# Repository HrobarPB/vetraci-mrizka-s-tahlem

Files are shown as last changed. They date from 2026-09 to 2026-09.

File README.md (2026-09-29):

# Větrací mřížka s žaluzií ovládanou táhlem zespodu

Plastová větrací mřížka **180 × 250 mm** s nastavitelnou žaluzií, podobná
typu *Dalap GP 180×250 s mechanicky ovládanou žaluzií*. Rozdíl je v ovládání:
místo páčky na mřížce **visí ze spodku rámu otočná tištěná tyč s rukojetí**,
takže mřížku ve výšce ovládne i menší člověk ze země.
Tyč je při pohledu zepředu **vlevo**. Na pravou stranu ji přepne parametr
`ovladani = "vpravo"`.

- rukojetí se otáčí o **půl otáčky**, tři polohy jsou po čtvrtotáčkách:
  **0° zavřeno, 90° napůl, 180° otevřeno**; šipka na rukojeti ukazuje, kde
  mřížka je
- v každé poloze je **zastavovací ploška**, lamely tam drží samy a nic je
  nestáhne dolů; konce drážky jsou pevné dorazy
- tyč se jen otáčí, nahoru ani dolů se nehýbe
- všechny díly mechanismu včetně tyče se **tisknou**, nic se nekupuje
- vzadu je **pevný rošt** a za ním **síťka proti hmyzu**, kupovaná nebo tištěná
- mřížka má dvě části: **montážní deska** zůstává na zdi, **přední kryt**
  s lamelami se sundá po pootočení 4 tištěných zámků, třeba kvůli výměně síťky

Model je parametrický (OpenSCAD) a všechny díly se tisknou **bez podpěr**.

| Otevřeno | Zavřeno | Mechanismus (boční řez) |
|---|---|---|
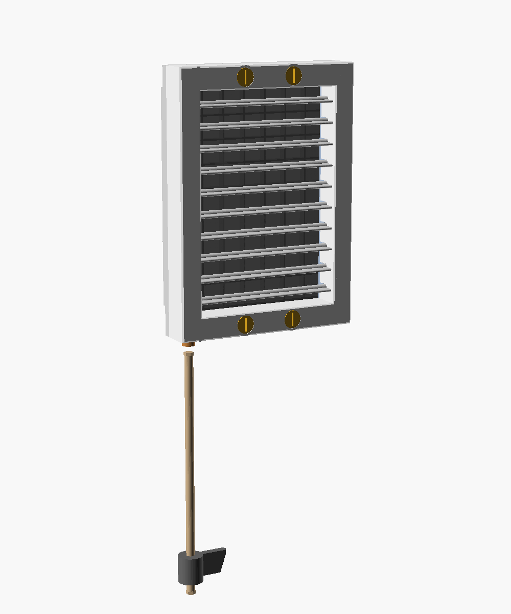
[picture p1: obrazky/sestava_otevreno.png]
otevřeno
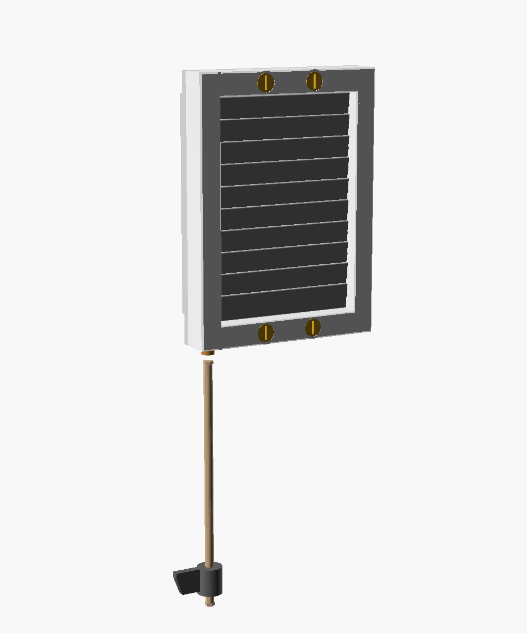
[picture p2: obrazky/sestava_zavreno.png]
zavřeno
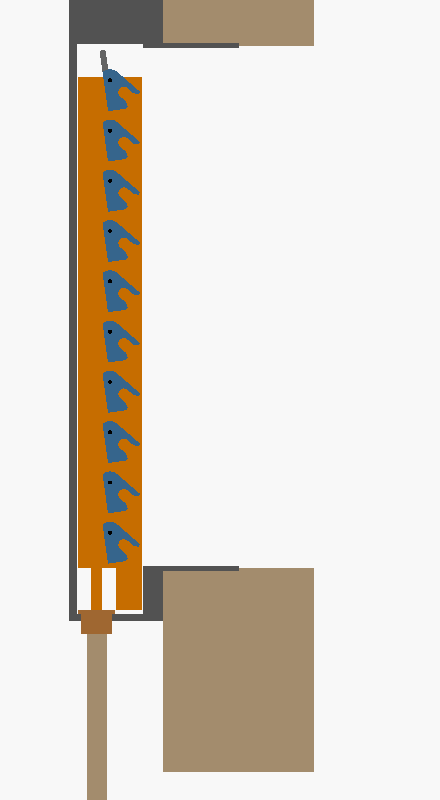
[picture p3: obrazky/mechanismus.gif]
animace
|  |  |  |

## Jak to funguje

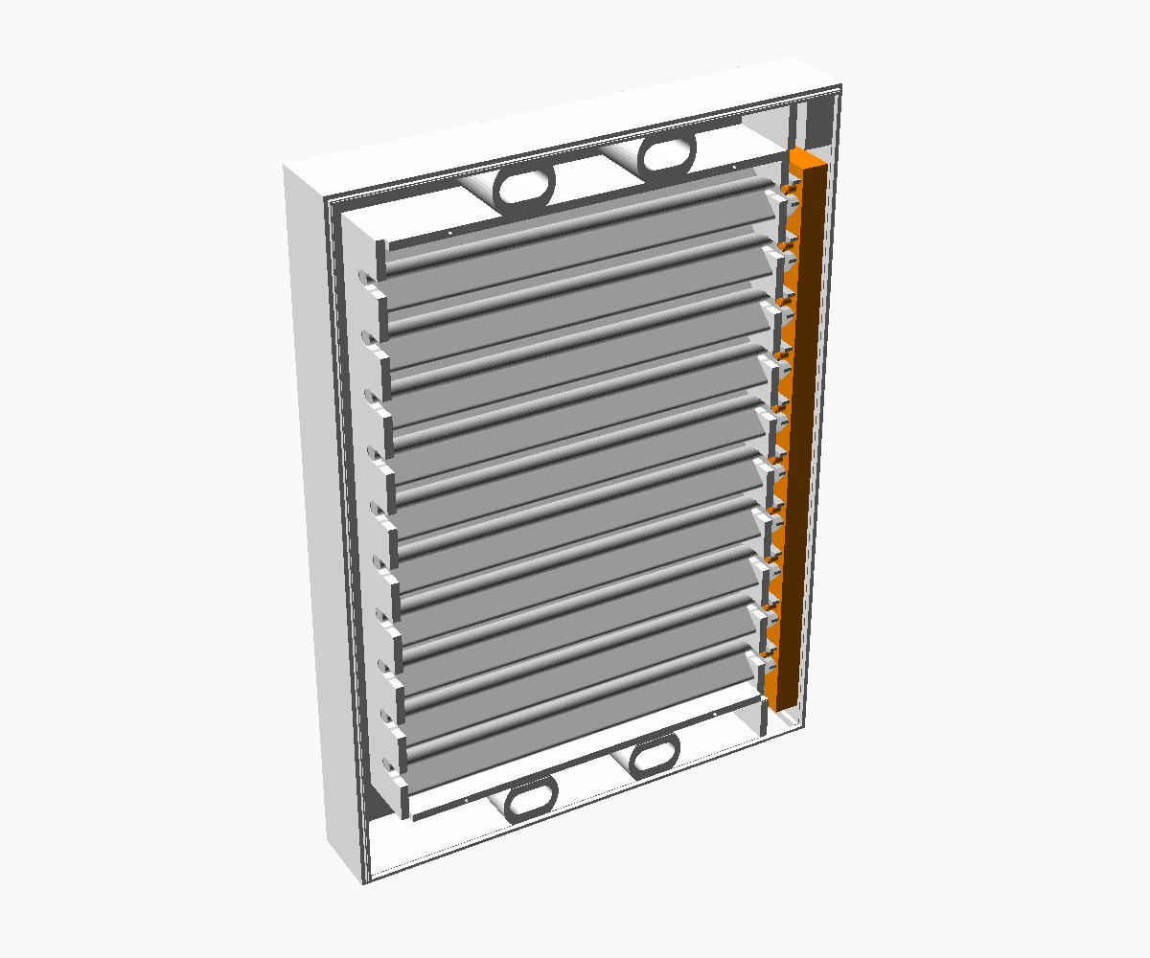
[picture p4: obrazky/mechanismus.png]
mechanismus zezadu


1. Deset vodorovných lamel se otáčí na čepech v rámu.
2. Na konci u táhla má každá lamela **vidlicové rameno** s rozšířeným ústím.
   Rameno je schované v boční komoře rámu, zepředu ho není vidět.
3. V komoře jezdí svislá **ovládací lišta** (oranžová). Její čepy zapadají
   do vidlic všech lamel najednou.
4. Lišta se pohybuje jen nahoru a dolů, **zdvih je 13 mm**. Lamely se přitom
   otočí o 82° z vodorovné polohy do téměř svislé a zavřené lamely se
   překrývají.
5. Pod lištou stojí na dně komory **rotační klín** (vačka): plný kotouč
   Ø 15 mm, stejný princip jako revolverový hloubkový doraz horní frézky.
   Nahoře má vyříznuté ploché stupně a šikmé náběhy a lišta na něm stojí
   **masivní nohou** (6 × 4 mm) s klínovou patkou. Když se kotouč otočí,
   noha vyjede po náběhu na vyšší stupeň nebo sjede na nižší.
6. Kotouč má tři vodorovné **stupně**: v poloze 0° (zavřeno), 90° (napůl)
   a 180° (otevřeno), mezi nimi jsou náběhy asi 40°. Lišta stojí na stupni
   vlastní vahou, takže v otevřené poloze stojí na nejvyšším stupni
   a nemá kam sjet. Když se rukojeť pustí mezi polohami, lišta po náběhu
   sama sjede na nejbližší nižší stupeň. Zbytek kotouče, kam noha nikdy
   nedojede, je plný a o 3 mm vyšší než nejvyšší stupeň: o něj noha za 0°
   a za 180° narazí (pevné dorazy).
7. Kotouč má dole čep, který prochází drážkou ve dně rámu, shora ho
   přitlačuje lišta. Váha tyče visí na kotouči, ne na liště.
8. Do čepu kotouče se zespodu zacvakne **tištěná tyč**: kulatá Ø 8 mm,
   jen konce jsou šestihranné (8 mm přes plošky). Tyč je složená z dílů,
   které se spojují tištěnými **spojkami**, dole je **rukojeť**
   s křidélkem na jednu stranu a šipkou.

Rozložená sestava:

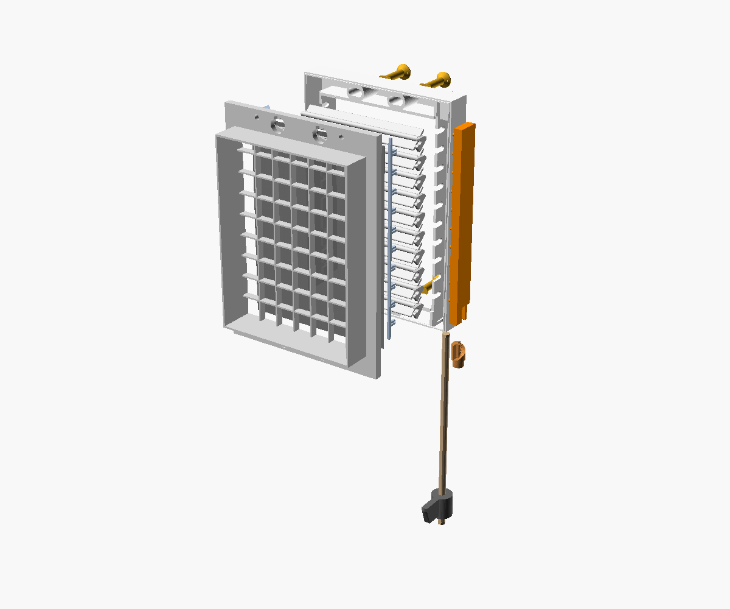
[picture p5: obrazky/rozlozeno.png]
rozloženo


## Rozměry (výchozí nastavení)

| | |
|---|---|
| vnější rozměr rámu | 180 × 250 mm |
| vystoupení ze zdi | 37,5 mm (přední kryt 29,5 + montážní deska 8) |
| světlý průduch (lamely) | 140 × 206 mm |
| otvor ve zdi (zadaný) | 158 × 208 mm |
| límec do otvoru ve zdi | 156 × 206 mm (vůle 1 mm na stranu), **stěny 2 mm**, hloubka 30 mm |
| rošt v montážní desce | 152 × 202 mm, oka cca 22 × 22 mm, žebra 1,6 mm |
| síťka proti hmyzu | přes celý otvor v límci, ustřihnout na **159 × 211 mm** |
| lamely | 10 ks, rozteč 20 mm, šířka 25 mm |
| zdvih lišty | 13 mm, polohy 0° / 90° / 180° |
| osa tyče | vlevo, 11 mm od levého okraje a 26,6 mm od zdi |
| vruty do zdi | 4× Fischer DuoPower 8 × 65 S jen skrz montážní desku, rozteč 100 mm vodorovně a 234 mm svisle, osa 8 mm od horní/dolní hrany (13 mm od otvoru ve zdi) |
| přední kryt k montážní desce | 4 otočné zámky na čtvrt otáčky: šroubovitý náběh, půlkruhová aretace, dorazy; rozteč 50 mm |

> **Otvor ve zdi** je nastavený na 158 × 208 mm (`otvor_sirka`,
> `otvor_vyska`). Límec se podle něj spočítá sám, o 1 mm na každou stranu
> menší (`limec_vule`).

## Díly k tisku

Hotová STL jsou ve složce [`stl/`](stl). Jsou už natočená do tiskové polohy.

| Díl | Soubor | Ks | Poznámka k tisku |
|---|---|---|---|
| Přední kryt (rám) | `ram.stl` | 1 | lícem dolů, potřebuje podložku aspoň **180 × 250 mm** |
| Montážní deska s límcem a roštem | `zadni_deska.stl` | 1 | deskou dolů; pro kupovanou síťku |
| *nebo* montážní deska s tištěnou síťkou | `zadni_deska_se_sitkou.stl` | 1 | místo předchozí; deskou dolů, viz [Síťka proti hmyzu](#síťka-proti-hmyzu) |
| Lamela | `lamela.stl` | **10** | rovnou stranou dolů, rameno nahoru |
| Ovládací lišta | `lista.stl` | 1 | naležato, čepy nahoru |
| Vačka (stupňový doraz) | `vacka.stl` | 1 | nastojato, čepem dolů; 4 perimetry, výplň 100 % |
| Pojistný hřebínek u táhla | `pojistka_u_tahla.stl` | 1 | naležato |
| Pojistný hřebínek protější (se žebry) | `pojistka_protejsi.stl` | 1 | naležato, žebry nahoru |
| Díl tyče (kulatá Ø 8, šestihranné konce, 230 mm) | `tyc.stl` | podle výšky (viz níže) | naležato na plošce; 4 perimetry |
| Spojka dílů tyče | `spojka.stl` | o 1 méně než dílů tyče | nastojato |
| Rukojeť se šipkou | `rukojet.stl` | 1 | zásuvkou nahoru |
| Vodítko tyče na zeď | `voditko.stl` | 0–2 | volitelné, když se tyč při točení moc houpe |
| Otočný klíč zámku | `klic.stl` | **4** | nastojato na rovné straně příčky, hlavou nahoru, bez podpěr; 4 perimetry, výplň 100 % |

**Materiál:** PETG (do interiéru) nebo ASA (na přímé slunce, originál je
také z ASA). PLA nedoporučuji, protože pružné díly (hroty tyče, hřebínky)
z PLA časem povolí nebo prasknou.
**Nastavení:** vrstva 0,2 mm, 3 perimetry, výplň 20 %, **bez podpěr**.
Lištu tiskněte se 4 perimetry, vačku a díly tyče se 4 perimetry a 100 %
výplní (přenášejí otáčení).

## Co koupit

| Položka | Ks | Kde koupit (příklady) |
|---|---|---|
| Hmoždinka **Fischer DuoPower 8 × 65 S** (balení obsahuje zápustné vruty **5 × 80**) | 4 | [KUTIL.cz](https://www.kutil.cz/spojovaci-material-a-kotevni-technika/kotevni-technika/vseobecne-hmozdinky/hmozdinka-duopower-fischer-8x65-1/), [srovnání cen na Heureka](https://www.heureka.cz/?h%5Bfraze%5D=hmo%C5%BEdinka+duopower+fischer+8x65), [technický list Fischer](https://www.fischer-cz.cz/cs-cz/products/bezne-hmozdinky/plastove-hmozdinky/duopower/538256-duopower-8x65-s) |
| Síť proti hmyzu, sklolaminátová, metráž (stačí kus 16 × 22 cm) | 1 | [UNI HOBBY – metráž šedá](https://unihobby.cz/sit-proti-hmyzu-sklovlaknita-metraz-seda), [BAUHAUS – sítě proti hmyzu](https://www.bauhaus.cz/site-proti-hmyzu-245270), [OBI – sítě proti hmyzu](https://www.obi.cz/ochrana-proti-hmyzu/ochranne-site-proti-hmyzu/c/2200), [Onpira – metráž](https://www.onpira.cz/zbozi/site-proti-hmyzu-skelne-vlakno/) |
| Vodítko (volitelné): 2 vruty 3,5 × 30 mm a hmoždinky 5 mm | 2 | [Heureka – hmoždinka 5 mm s vrutem](https://www.heureka.cz/?h%5Bfraze%5D=hmo%C5%BEdinka+5+mm+s+vrutem) |

Mechanismus i tyč jsou celé tištěné, na ovládání se nic nekupuje.

### Délka tyče

Tyč se skládá z dílů `tyc.stl` (každý 230 mm, parametr `tyc_dil`), mezi nimi
jsou spojky a dole rukojeť:

```
vzdálenost od spodku mřížky ke spodku rukojeti ≈ počet dílů × 233 mm + 17 mm
```

Příklad: mřížka má spodek ve 240 cm, rukojeť má být kolem 150 cm, tedy
90 cm: **4 díly** (949 mm, rukojeť ve 145 cm) a 3 spojky. Na přesnou délku
změňte `tyc_dil` (třeba 4 díly po 215 mm) a díly přegenerujte.

## Sestavení předního krytu

1. **Očistěte díly.** Lamela se musí v drážkách „U“ rámu otáčet volně. Když
   drhne, přejeďte čepy smirkem. Kotouč dorazu se musí volně otáčet
   v drážce ve dně.
2. Rám položte **lícem dolů** na stůl. Komora mechanismu je teď při pohledu
   zezadu **vpravo**.
3. **Vložte kotouč dorazu:** zezadu ho zasuňte čepem do drážky ve dně
   komory (kotouč projde výřezem ve spodku přepážky). Natočte ho do polohy
   **90°** (napůl): prostřední stupeň je na straně u vnější stěny rámu.
4. **Vložte lamely** jednu po druhé zezadu, čepem do drážek „U“. Každou
   natočte **napůl** (asi 41° od vodorovné), tak aby otevřená vidlice ramene
   mířila **rovně dozadu**, tedy kolmo od stolu nahoru.
5. **Zasuňte lištu** zezadu do komory, čepy k lamelám, nohou dolů. Čepy vjedou do vidlic všech lamel najednou (ústí vidlic jsou
   rozšířená, takže lamely nemusí být natočené přesně) a noha dosedne
   na prostřední stupeň kotouče.
6. **Zatlačte oba pojistné hřebínky** do vybrání na horní hraně přepážek,
   až **cvaknou**. Jejich prsty zajistí čepy lamel v drážkách. Každý prst je
   rozdělený na dvě pružné poloviny s výstupky, které zapadnou do drážek ve
   stěnách krytu, takže hřebínek drží i v sundaném krytu. Vytáhnout se dá
   silou (výstupky mají šikmé boky). Sílu západky mění `hrebinek_zapadka`.

   Hřebínky jsou dva různé díly. `pojistka_u_tahla` patří na přepážku vedle
   mechanismu (při táhle vlevo je to levý). `pojistka_protejsi` patří na
   volně stojící stěnu průduchu na druhé straně (při táhle vlevo pravý).
   Ten má navíc žebra, která vyplní mezeru mezi stěnou průduchu a vnější
   stěnou krytu a opřou se o ni. Hřebínek se tak nemůže naklonit ani
   posunout do strany a výstupky prstů nevyskočí z drážek. Žebra jsou mezi
   prsty, takže prsty dál pruží.

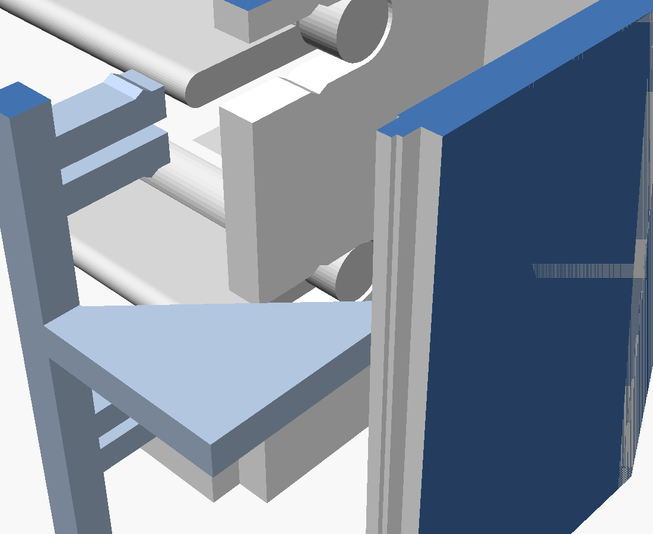
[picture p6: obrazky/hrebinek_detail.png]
detail západky hřebínku
   

   *Hřebínek (modrý) vytažený z krytu: každý prst je rozdělený na dvě pružné
   poloviny s výstupky, ve stěnách drážek „U“ v krytu jsou proti nim drážky.*
7. **Vyzkoušejte chod:** otáčejte kotoučem za čep, který vyčnívá zespodu
   rámu (rám držte svisle, jak bude na zdi, lišta stojí vlastní vahou).
   Na 0°, 90° a 180° musí lamely zůstat stát, mezi nimi se musí otáčet
   všechny současně a lehce.
8. **Klíče zámků** (bez lepidla a bez šroubů) se zasouvají až při nasazení
   krytu na montážní desku, viz [Montáž na zeď](#montáž-na-zeď-fischer-duopower-8--65-s),
   krok 6.

## Zámek krytu (jak funguje)

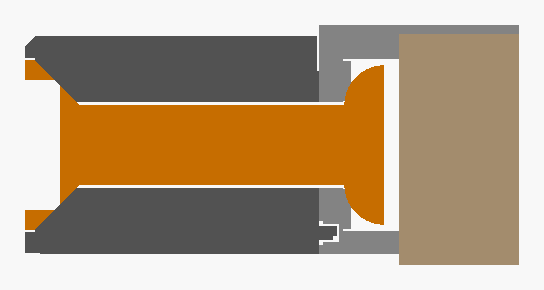
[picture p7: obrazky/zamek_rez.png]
řez zámkem v zamčené poloze


*Řez osou zámku: vlevo zápustná hlava klíče v líci krytu, kulatý dřík skrz kryt,
vpravo půlkulatá příčka za plným dnem zámku v montážní desce, úplně vpravo zeď.*

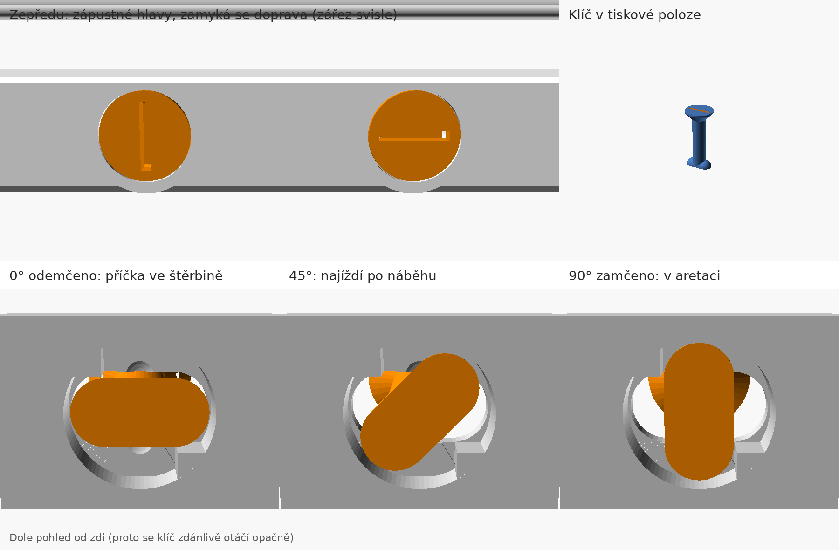
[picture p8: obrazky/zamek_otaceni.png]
otáčení klíče


*Nahoře zepředu: hlavy klíčů (Ø 17 mm) jsou zapuštěné a zarovnané s lícem
krytu a otáčejí se v kuželovém lůžku; zářez svisle = zamčeno, vodorovně =
odemčeno. Vpravo klíč v tiskové poloze. Dole pohled od zdi do montážní
desky: příčka se otáčí v kulaté kapse montážní desky za krytem, v krytu je jen
kulatý dřík. Vodorovnou štěrbinu v krytu hlava zakryje v každé poloze.*

Zámek je udělaný jako současné vačkové zámky na čtvrt otáčky (např. u
rozvaděčů): příčka po **šroubovitém náběhu** postupně přitáhne kryt, na konci
zapadne do **aretace** a **doraz** nedovolí přetočení. Všechny tvary, které
se o sebe opírají, jsou **zaoblené (půlkulaté)**: nemají ostré hrany, které
by soustředily napětí a vyrývaly se do plastu.

- **Klíč:** zápustná kulatá hlava Ø 17 mm se zkosením 45° sedí v kuželovém
  lůžku v líci krytu, zarovnaná s lícem, a sama se vystředí. Kulatý dřík
  Ø 8 mm a **půlkulatá příčka** (Ø 8 mm, rovnou stranou ke zdi, zaoblené
  konce). Tiskne se nastojato na rovné straně příčky, hlavou nahoru, bez
  podpěr. Průřez dříku Ø 8 mm unese v tahu i napříč vrstvami řádově přes
  1000 N, zámek přitom nese jen desítky N.
- **Náběh:** za vodorovnou štěrbinou v montážní desce je plné dno 2,4 mm,
  pevně spojené se zbytkem desky a tištěné celou plochou na podložce, a na
  něm šroubovitý náběh. Příčka se točí v kulaté kapse, okolo je deska plná
  až k okraji. Příčka po náběhu najíždí a kryt se přitáhne.
- **Aretace:** v zamčené poloze příčka zapadne do půlkruhového lůžka
  vytvarovaného přesně podle ní a zámek **cvakne**. Přesah 0,3 mm drží
  kryt přitažený. Aby se zámek povolil, musí příčka vyjet zpátky přes
  hranu aretace (0,35 mm), takže se sám neotevře.
- **Dorazy:** klíč se točí jen jedním směrem a jen o čtvrt otáčky. Dorazy
  jsou plné bloky přes celou hloubku kapsy (až po zadní plochu desky),
  srostlé s její stěnou a s rovným čelem, takže se přes ně oblá příčka
  nepřetlačí.
- **Stejný směr zasunutí:** štěrbina v krytu i v montážní desce je
  vodorovná, klíč se zasune skrz oba díly najednou.
- **Obvodová polodrážka (lip and groove):** zadní hrana stěn krytu má po
  celém obvodu límeček 1,4 × 1,8 mm se zúženou špičkou a v čele montážní
  desky je pro něj drážka s vůlí 0,2 mm. Kryt se na desce vystředí ve
  všech směrech dřív, než se zasunou klíče, takže štěrbiny v obou dílech
  jsou přesně proti sobě. Spára mezi díly je navíc zakrytá.
- **Ovládání:** mincí nebo plochým šroubovákem v hlubokém zářezu (3,5 mm);
  zamyká se **doprava** (po směru hodin při pohledu zepředu); zářez **svisle = zamčeno**,
  **vodorovně = odemčeno**.

Zámek je tuhý (nic v něm nepruží), proto rozhoduje přesnost tisku. Nejdřív
vytiskněte jeden klíč a kousek desky se zámkem. Když jde zámek moc ztuha,
zmenšete `klic_predpeti` (např. 0,15) a `aretace_hl` (např. 0,2); když kryt
drží volně, `klic_predpeti` zvětšete.

## Montáž na zeď (Fischer DuoPower 8 × 65 S)

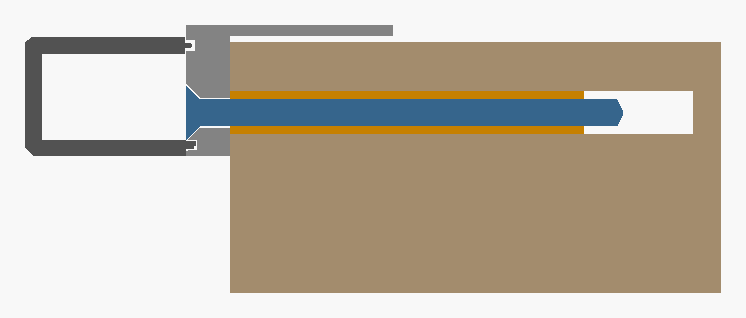
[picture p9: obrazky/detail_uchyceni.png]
detail uchycení


Na zeď se přišroubuje jen **montážní deska** (8 mm). Zápustné hlavy vrutů
5 × 80 jsou v rovině jejího čela, takže je přední kryt zcela zakryje. Vrut
jde do hmoždinky 72 mm (Fischer předepisuje aspoň 70 mm).

1. Montážní desku zasuňte límcem do otvoru ve zdi a srovnejte do vodováhy.
   Skrz 4 otvory označte místa pro hmoždinky a desku sundejte.
2. Vyvrtejte díry **Ø 8 mm, hloubka aspoň 85 mm**. Do cihly a porobetonu
   vrtejte bez příklepu. Vyfoukejte prach.
3. Hmoždinky zatlučte **do roviny zdi**.
4. Montážní desku přišroubujte vruty 5 × 80. Hlavy musí zapadnout do
   zahloubení v rovině čela desky.
5. **Síťka:** kupovanou síťku 159 × 211 mm nabodněte na 4 malé trny na zadní
   straně předního krytu (u horního a dolního okraje průduchu). Trny ji
   drží, takže při nasazování nespadne. (U montážní desky s tištěnou síťkou
   tento krok odpadá.)
6. **Nasaďte přední kryt** na montážní desku tak, aby límeček na zadní
   hraně krytu zapadl po celém obvodu do drážky v desce. Pak do každého otvoru v líci krytu zasuňte klíč
   se zářezem **vodorovně** (příčka projde vodorovnou štěrbinou v krytu
   i v desce, hlava zapadne do zápustného lůžka). Klíč přitlačte a otočte
   mincí nebo šroubovákem o **čtvrt otáčky doprava** (po směru hodin), až
   je zářez **svisle** a zámek cvakne. Zářez v hlavě klíče je 3,5 mm
   hluboký, mince nebo šroubovák se do něj dobře opře.
7. **Tyč:** díly tyče zasuňte do spojek a dole do rukojeti, až **cvaknou**
   (hroty jsou rozdělené a mají západky). Horní hrot zasuňte zespodu do
   čepu kotouče, až cvakne. Šestihran jde zasunout v šesti natočeních: když
   jsou lamely zavřené (0°, kotouč na dorazu), zasuňte rukojeť tak, aby
   šipka mířila **dopředu od zdi**. Po čtvrt otáčce (šipka do strany) je
   mřížka **napůl**, po půl otáčce (šipka **ke zdi**) **otevřená**. Opačným
   směrem se rukojeť neotočí, drží ji doraz ve vačce. Pevným tahem jdou
   hroty zase vytáhnout.
8. Pokud se tyč při točení houpe, přišroubujte doprostřed její délky
   **vodítko**. Tyč se do něj dá zacvaknout i dodatečně.

> ⚠️ **Vzdálenost od okraje otvoru ve zdi.** Otvor 208 mm je vysoký, nad ním
> i pod ním zbývá v mřížce 250 mm jen 21 mm. Vruty jsou proto co nejblíž
> vnější hraně desky (osa 8 mm od hrany, dál to nejde kvůli hlavě vrutu):
> osa hmoždinky je 13 mm od otvoru a mezi vývrtem Ø 8 a otvorem zbývá
> **asi 9 mm zdiva**. Vrtejte bez příklepu a vruty utahujte citlivě.
> Minimální vzdálenost od okraje pro váš materiál uvádí technický list
> Fischer. Víc místa dá jen vyšší mřížka (`vyska`), ta se ale nad 250 mm
> nevejde na běžné tiskové podložky. Model při změně parametrů vypíše,
> kolik zdiva zbývá.

## Síťka proti hmyzu

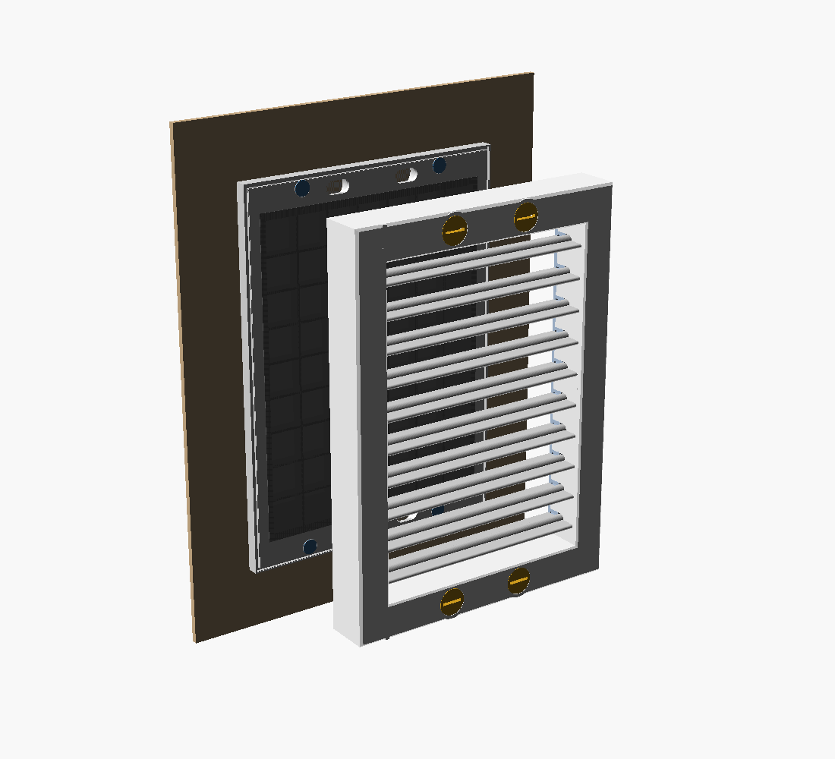
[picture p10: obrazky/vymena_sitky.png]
výměna síťky: montážní deska na zdi, přední kryt sundaný


| Zezadu | Rozloženo (tištěná síťka) |
|---|---|
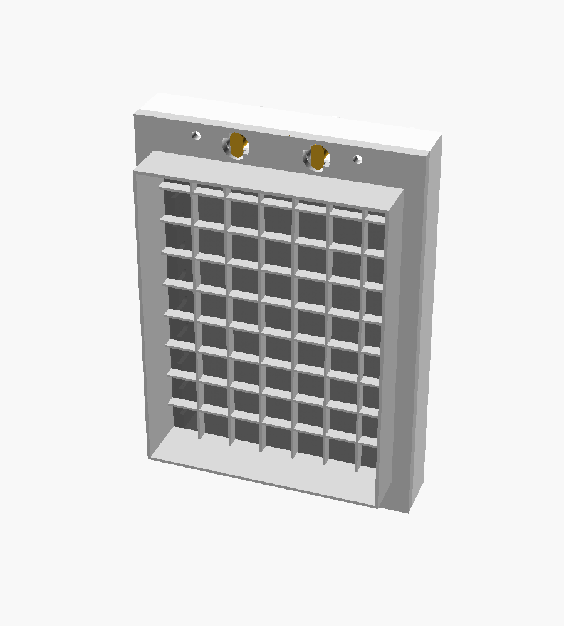
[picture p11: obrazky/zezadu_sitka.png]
zezadu
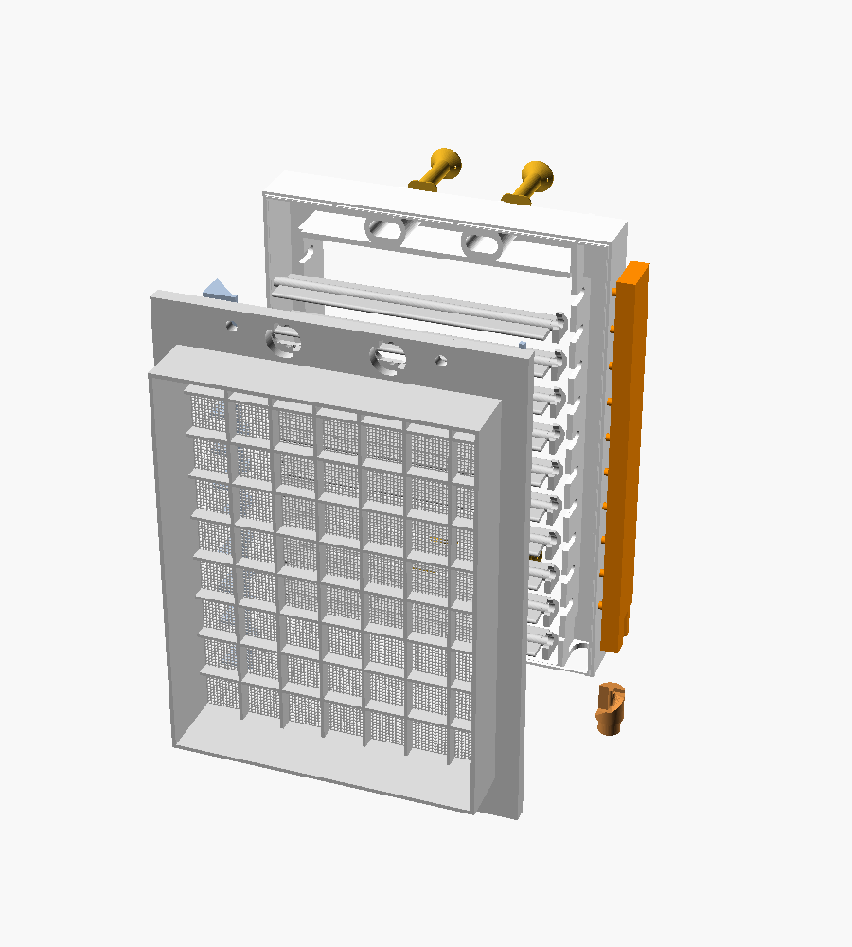
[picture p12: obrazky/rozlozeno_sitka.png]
rozloženo se síťkou
|  |  |

Síťka je **uprostřed mřížky, sevřená mezi předním krytem a montážní
deskou**. Drží ji po celém obvodu 4 otočné klíče, takže nemůže vypadnout ani
se po okraji vysunout. Hned za ní je **pevný rošt** v montážní desce, který
ji podepře a nepustí dovnitř ptáky. Před ní je 1,5 mm volného místa
k lamelám.

**Výměna nebo vyčištění síťky:** mincí otočte 4 klíče zářezem vodorovně,
vytáhněte je, vytáhněte tyč z čepu kotouče a přední kryt sundejte. Montážní deska zůstane na zdi a síťka je
hned přístupná.

**Kupovaná síťka:** ze sklolaminátové sítě proti hmyzu ustřihněte obdélník
**159 × 211 mm** (pokryje celý otvor v límci). Přední kryt má pro síťku lůžko hluboké 0,25 mm, takže ji
montážní deska pevně stiskne.

**Tištěná síťka:** vytiskněte `zadni_deska_se_sitkou.stl` místo
`zadni_deska.stl`. Síťka je plochá mřížka v prvních dvou vrstvách montážní
desky: vlákna v obou směrech leží celou plochou na podložce, nic nevisí ve
vzduchu. Oka 1,2 × 1,2 mm, tloušťka **0,8 mm (4 vrstvy po 0,2 mm)**, aby
se síťka při sundávání z podložky nelámala (parametr `tistena_tl`). Tiskne se deskou dolů na čistou
podložku, výška vrstvy **0,2 mm**, šířka extruze 0,45–0,5 mm, bez
„ironing“. Pokud slicer vlákna vynechá, zvětšete `tistena_vlakno` na 0,6.
Rozteč lze změnit parametrem `tistena_roztec`.

Rošt ubere asi 12 % průřezu, síťka proti hmyzu dalších zhruba 30–40 %.
S tím je potřeba počítat, pokud je větrání na hraně.

## Úpravy modelu

Otevřete `mrizka.scad` v [OpenSCAD](https://openscad.org) (2021.01 nebo
novější). V panelu *Customizer* lze měnit hlavně:

- `ovladani`: strana táhla při pohledu zepředu (`vlevo` nebo `vpravo`)
- `sirka`, `vyska`: vnější rozměr rámu
- `pocet_lamel`, `roztec`, `sirka_lamely`: počet a velikost lamel.
  Světlý průduch a okraje se dopočítají samy.
- `otvor_sirka`, `otvor_vyska`: světlý otvor ve zdi; límec se spočítá sám
  (`limec_vule`), nebo ho zadejte ručně (`limec_sirka`, `limec_vyska`)
- `vrut_od_okraje`: vzdálenost vrutu od hrany desky (menší = dál od otvoru)
- `tl_desky`, `roztec_sroubu`, `hlava_sroubu`: montážní deska a vruty do
  zdi (výchozí hodnoty pro Fischer DuoPower 8 × 65 S s vrutem 5 × 80)
- `roztec_klicu`, `klic_predpeti`, `aretace_hl`, `dno_zamku`: zámky předního krytu
  (viz [Zámek krytu](#zámek-krytu-jak-funguje))
- `bok_protejsi`: šířka bočního okraje bez mechanismu (výchozí 20 mm = souměrný kryt)
- `hrebinek_zapadka`: výška výstupků západky pojistných hřebínků
- `sitka`: `kupovana`, `tistena` nebo `zadna`; `sitka_tl`: hloubka lůžka
  pro kupovanou síťku; `rost_roztec`, `rost_zebro`: pevný rošt;
  `tistena_roztec`, `tistena_vlakno`: tištěná síťka
- `tyc_s`, `tyc_dil`: tyč (šestihran konců přes plošky, délka dílu)
- `vacka_ploska`: šířka stupňů kotouče dorazu ve stupních (na každou stranu)
- `dil`: co se vykreslí (sestava, řez, schéma, rozložený pohled nebo
  jednotlivé díly pro tisk)
- `otevreni`: poloha žaluzie v náhledu (0 až 1)

Model obsahuje kontroly (`assert`), které upozorní na nesmyslnou kombinaci
parametrů.

**Kontrola kolizí a přegenerování STL a obrázků:**

```bash
./skripty/export.sh                              # výchozí rozměry
./skripty/export.sh -D vyska=300 -D pocet_lamel=12   # vlastní rozměry
```

Skript nejdřív spustí `kontrola.scad`. Ta ve 41 polohách mezi zavřeno
a otevřeno ověří, že lamely nenarážejí do sebe ani do rámu, ramena nenarážejí
do komory ani do kotouče dorazu, čepy lišty zůstávají
v rovné části vidlic a lišta nenarazí na kotouč ani horní doraz. Teprve potom skript
vygeneruje STL, obrázky a animaci.

## Ladění

- **Rukojeť jde ztuha:** přejeďte smirkem stupně a náběhy kotouče a patku
  lišty, zkontrolujte, že se kotouč volně točí v drážce ve dně.
- **Lišta nesjíždí dolů na nižší stupeň:** lamely drhnou, uvolněte je
  (čepy v drážkách „U“, vidlice).
- **Hrot tyče drží v zásuvce málo nebo moc:** výšku západek mění `zub_v`
  v sekci *Hidden*.
- **Lamely drhnou:** zvětšete vůle, tedy `r_osa + 0.2` v drážkách „U“,
  nebo zabruste čepy.
- **Zavřené lamely nedoléhají:** úhel `uhel_zavreni` lze zvednout až k mezi,
  kterou hlídá `assert` (výchozí 82° nechává mezi lamelami 0,4 mm).

## ⚠️ Důležité upozornění

Pokud mřížka přivádí **spalovací vzduch pro plynový spotřebič** (kotel,
karma, sporák v bytě s komínovým spotřebičem), **nesmí být uzavíratelná**.
Plynárenská pravidla (TPG 704 01) uzavíratelné větrací otvory pro přívod
spalovacího vzduchu nepovolují. Tuto mřížku tam nepoužívejte. Hrozí otrava
oxidem uhelnatým.

## Alternativy ovládání

Kdyby tyč překážela, dá se vytáhnout z čepu kotouče a nosit zvlášť jako
klíč: zasune se jen při ovládání.

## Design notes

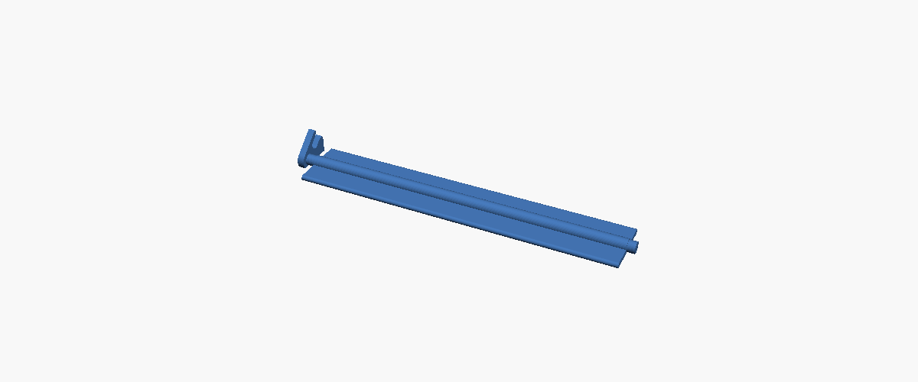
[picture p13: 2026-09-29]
obrazky/lamela.png

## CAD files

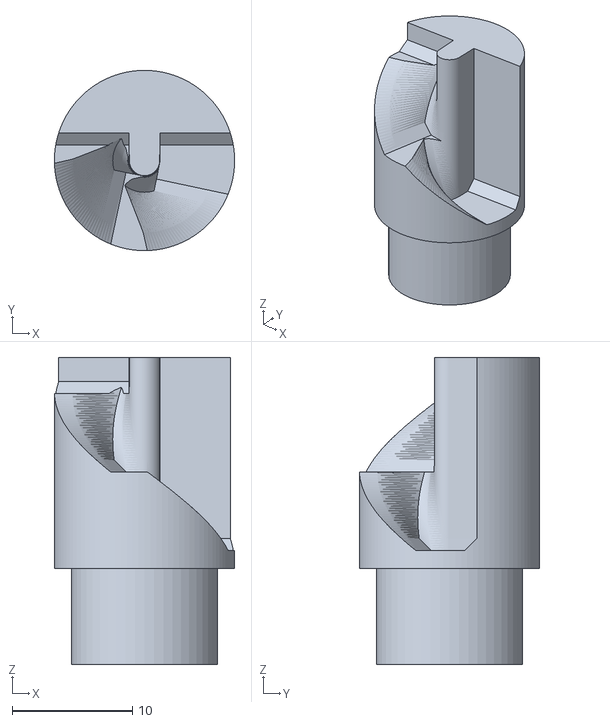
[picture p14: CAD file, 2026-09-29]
stl/vacka.stl
15.0 x 15.0 x 25.5

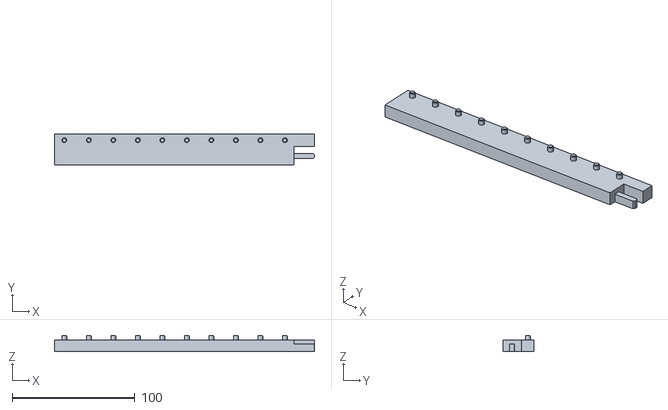
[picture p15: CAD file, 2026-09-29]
stl/lista.stl
212.2 x 25.5 x 13.2

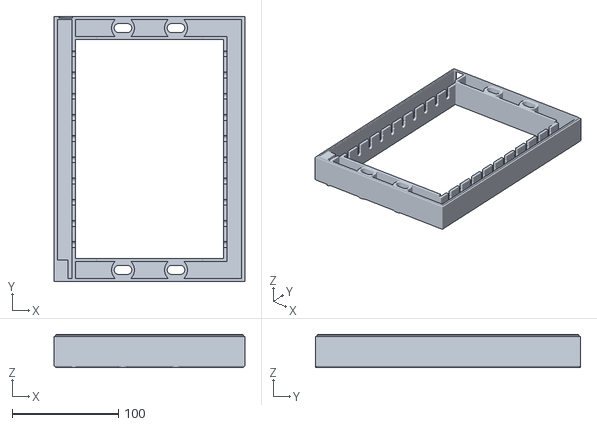
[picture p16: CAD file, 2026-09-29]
stl/ram.stl
180.0 x 250.0 x 31.3

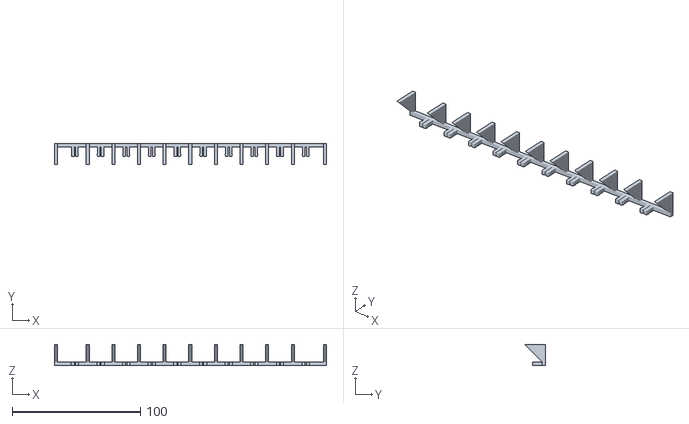
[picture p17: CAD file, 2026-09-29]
stl/pojistka_protejsi.stl
212.2 x 16.4 x 16.7

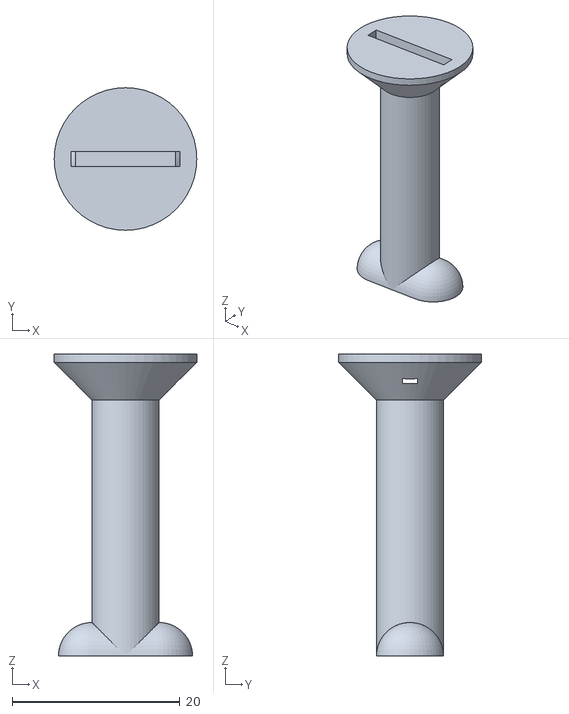
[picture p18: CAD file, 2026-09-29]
stl/klic.stl
17.0 x 17.0 x 36.0

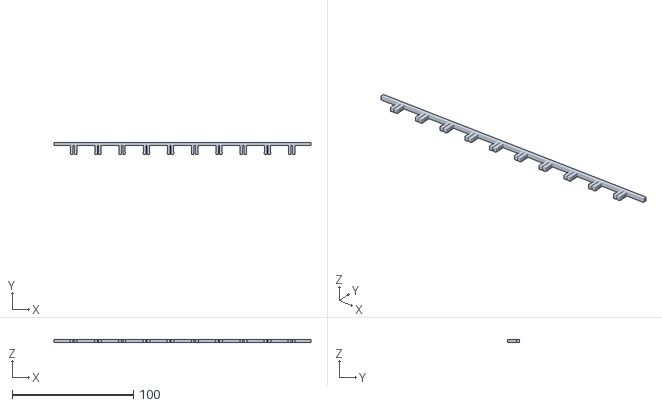
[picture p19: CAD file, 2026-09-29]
stl/pojistka_u_tahla.stl
212.2 x 10.2 x 2.80

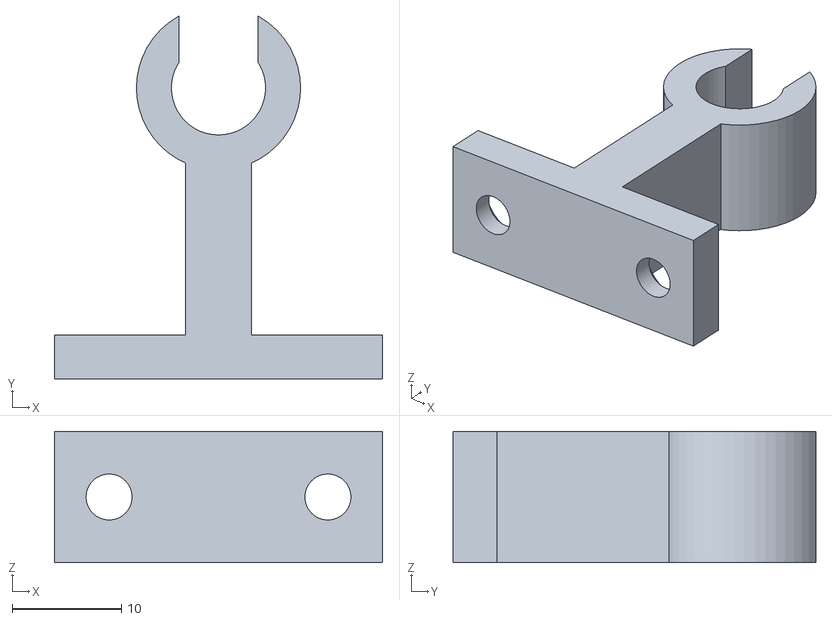
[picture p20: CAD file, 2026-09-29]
stl/voditko.stl
30.0 x 33.2 x 12.0

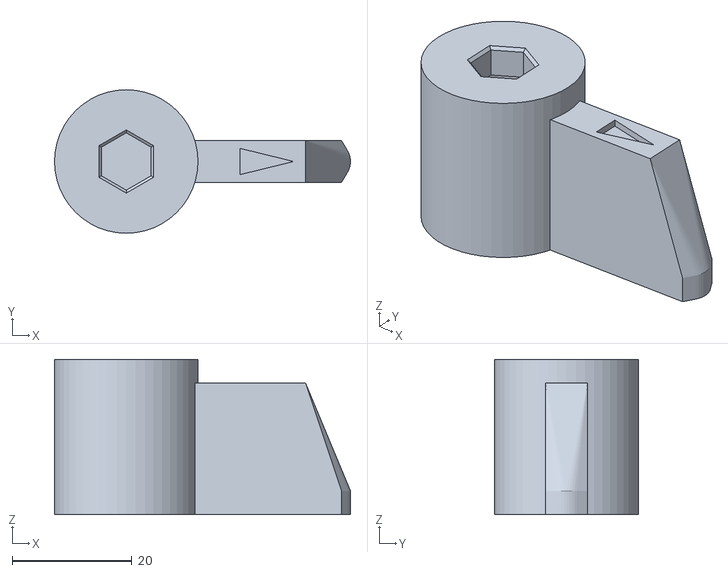
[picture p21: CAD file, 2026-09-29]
stl/rukojet.stl
49.5 x 24.0 x 26.0

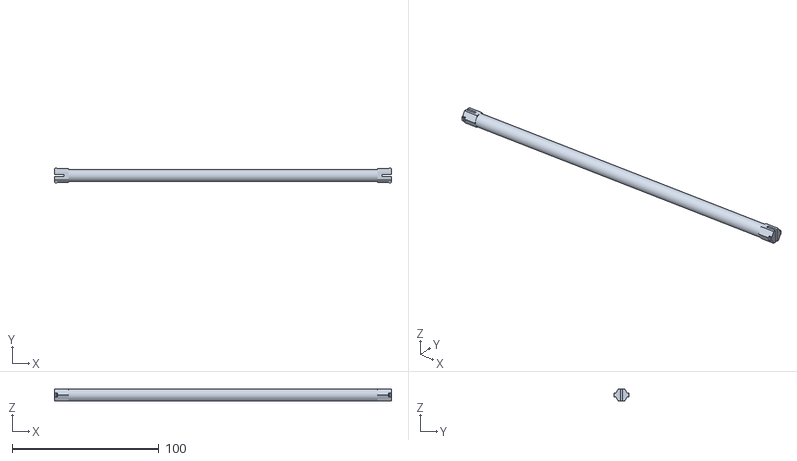
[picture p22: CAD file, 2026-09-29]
stl/tyc.stl
230.0 x 10.3 x 8.00

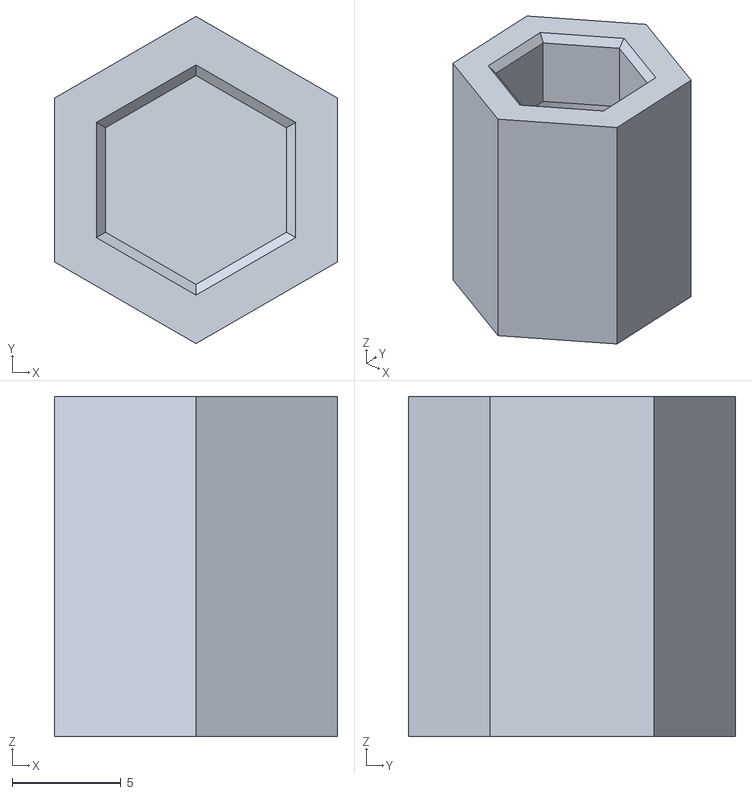
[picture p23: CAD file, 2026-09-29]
stl/spojka.stl
13.0 x 15.0 x 15.6

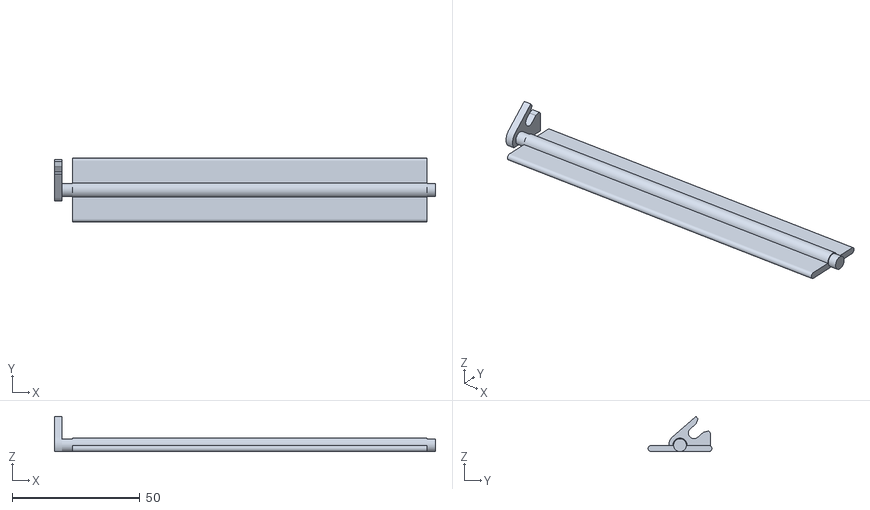
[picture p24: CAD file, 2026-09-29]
stl/lamela.stl
149.3 x 25.0 x 13.8

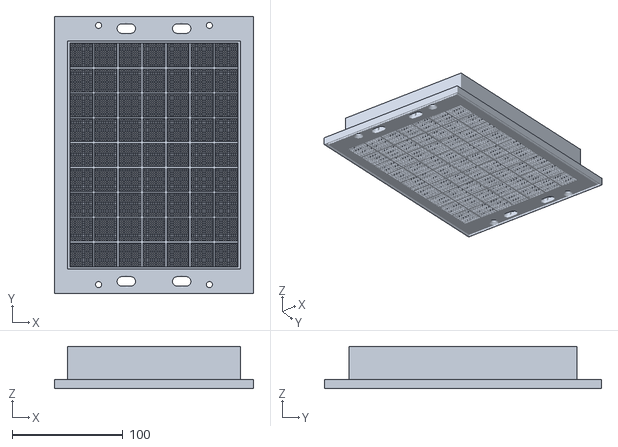
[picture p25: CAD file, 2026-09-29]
stl/zadni_deska_se_sitkou.stl
180.0 x 250.0 x 38.0

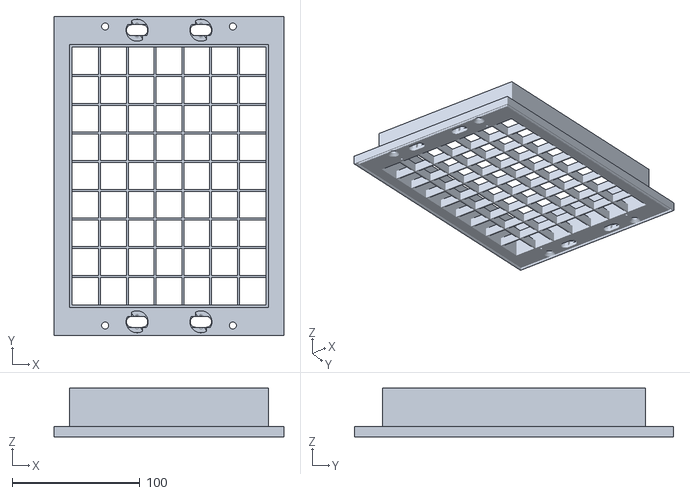
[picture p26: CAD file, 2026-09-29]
stl/zadni_deska.stl
180.0 x 250.0 x 38.0

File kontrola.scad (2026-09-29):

// Kontrola kolizí mechanismu v celém rozsahu pohybu (2D řezy).
// Výsledek musí být PRÁZDNÝ ("Current top level object is empty").
// Spuštění:  openscad -o kolize.svg kontrola.scad
include <mrizka.scad>
dil = "nic";
kroky = 40;
big = 1000;

module lamely2d(phi) for (i = [0:N-1]) translate([y_ax, zl(i)]) rotate(phi) lamela_profil();
module ramena2d(phi) for (i = [0:N-1]) translate([y_ax, zl(i)]) rotate(phi) rameno_profil();
module cepy2d(s) for (i = [0:N-1]) translate([y_pin, zl(i) + s]) circle(r = r_cep);

// stěny v řezu průduchem: horní a dolní okraj (vepředu je okno, vzadu otvor)
module steny_A() {
    translate([-big/2, -big]) square([big, big + tb - eps]);
    translate([-big/2, H - tb + eps]) square([big, big]);
    translate([-big, -big/2]) square([big + 0 - eps, 2*big]);          // před lícem (y < 0)
    translate([D + sd + limec_hloubka + eps, -big/2]) square([big, 2*big]);
}
// stěny v řezu ramen: čelo, zadní deska, dno, strop komory
module steny_B() {
    translate([-big, -big/2]) square([big + st - eps, 2*big]);
    translate([D + eps, -big/2]) square([big, 2*big]);
    translate([-big/2, -big]) square([big, big + st - eps]);
    translate([-big/2, H - st + eps]) square([big, big]);
}

// vačka a držák jejího horního čepu (pevné, v řezu komorou)
module vacka2d() translate([vk_y, 0]) {      // kotouč dorazu (plný až do výšky stěny) a horní čep
    translate([-vk_r, st]) square([2*vk_r, vk_W - st]);
}
module drzak2d() square(0);   // držák čepu kotouče už není
module lista2d(s) translate([y_bar0, bar_bot0 + s]) difference() {
    square([y_bar1 - y_bar0, bar_top0 - bar_bot0]);
    translate([-1, -1]) square([kz_y0 - y_bar0 + 1, lista_vybrani + 1]);
}

for (k = [0:kroky]) {
    phi = -phic*(1 - k/kroky);
    s = s_of(phi);
    translate([k*200, 0]) {
        intersection() { lamely2d(phi); steny_A(); }
        for (i = [0:N-2]) intersection() {
            translate([y_ax, zl(i)])   rotate(phi) lamela_profil();
            translate([y_ax, zl(i+1)]) rotate(phi) lamela_profil();
        }
        intersection() { ramena2d(phi); union() { steny_B(); vacka2d(); drzak2d(); } }
        intersection() { ramena2d(phi); cepy2d(s); }
        for (i = [0:N-2]) intersection() {
            translate([y_ax, zl(i)])   rotate(phi) rameno_profil();
            translate([y_ax, zl(i+1)]) rotate(phi) rameno_profil();
        }
        // lišta v komoře: stěny, horní doraz, vačka, držák čepu vačky
        intersection() {
            lista2d(s);
            union() { steny_B(); vacka2d(); drzak2d(); translate([-big/2, bar_top0 + s_max + 0.1 + eps]) square([big, big]); }
        }
        // čep musí zůstat v rovné části vidlice (ne v rozšířeném ústí)
        if (e/cos(phi + alpha) > L_arm - usti_l - 0.3) square(5);
    }
}

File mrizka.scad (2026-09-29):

// =====================================================================
//  Větrací mřížka s žaluzií ovládanou svislým táhlem zespodu
//  (parametrický model pro 3D tisk, OpenSCAD 2021.01+)
//
//  Princip: vodorovné lamely se otáčejí na čepech. Na konci u táhla má
//  každá lamela vidlicové rameno. Do vidlic zapadají čepy svislé
//  ovládací lišty, která jezdí jen nahoru/dolů ve skryté boční komoře.
//  Do spodku lišty se zasune tyčka (táhlo) Ø6 mm, která vede dolů
//  k ruce.  Nahoru = otevřít, dolů = zavřít.  Pružná západka na liště
//  drží polohy zavřeno / napůl / otevřeno.
//
//  Souřadnice:  X = šířka (zleva doprava při pohledu zepředu)
//               Y = hloubka (0 = přední líc, kladně směrem do zdi)
//               Z = výška
//  Geometrie je popsaná pro mechanismus vpravo; varianta "vlevo"
//  (parametr ovladani) vznikne zrcadlením celé sestavy.
// =====================================================================

/* [Zobrazení] */
// Co vykreslit (díly "..." jsou už natočené pro tisk)
dil = "sestava"; // [sestava, rez, schema, mechanismus, rozlozeno, ram, zadni_deska, lamela, lista, pojistka_u_tahla, pojistka_protejsi, vacka, tyc, spojka, rukojet, voditko, klic, detail_uchyceni, zamek_rez, hrebinek_detail, vymena_sitky]
// Poloha žaluzie: 0 = zavřeno, 1 = otevřeno
otevreni = 1; // [0:0.05:1]
// Na které straně (při pohledu zepředu na mřížku na zdi) je táhlo
ovladani = "vlevo"; // [vlevo, vpravo]
// Délka tyčky táhla pro náhled sestavy [mm]
nahled_delka_tycky = 250;

/* [Hlavní rozměry] */
// Vnější šířka rámu [mm]
sirka = 180;
// Vnější výška rámu [mm]
vyska = 250;
// Hloubka předního rámu (o kolik vystoupí ze zdi, bez zadní desky) [mm]
hloubka = 29.5;
// Tloušťka stěn a čelní plochy [mm]
stena = 3;
// Šířka bočního okraje (na straně táhla je v něm skrytá komora mechanismu) [mm]
bok = 20;
// Šířka bočního okraje na protější straně (bez mechanismu) [mm]; stejná jako na straně táhla = souměrný kryt
bok_protejsi = 20;

/* [Lamely] */
pocet_lamel = 10;
// Svislá rozteč os lamel [mm]
roztec = 20;
// Šířka (hloubka) lamely [mm]
sirka_lamely = 25;
tloustka_lamely = 2.4;
// Úhel natočení v zavřené poloze [°]  (musí platit roztec*cos(úhel) > tloušťka)
uhel_zavreni = 82;

/* [Otvor ve zdi, montážní deska a límec] */
// Světlý otvor ve zdi – šířka [mm]
otvor_sirka = 158;
// Světlý otvor ve zdi – výška [mm]
otvor_vyska = 208;
// Límec, který se zasune do otvoru ve zdi
limec = true;
// Vůle límce v otvoru na každou stranu [mm]
limec_vule = 1;
// Vnější šířka límce (0 = podle otvoru ve zdi) [mm]
limec_sirka = 0;
// Vnější výška límce (0 = podle otvoru ve zdi) [mm]
limec_vyska = 0;
limec_hloubka = 30;
limec_stena = 2;

/* [Síťka proti hmyzu] */
// Síťka sevřená mezi rámem a zadní deskou: kupovaná (ustřihnout na míru),
// tištěná (vytiskne se jako první vrstvy zadní desky), nebo žádná
sitka = "kupovana"; // [kupovana, tistena, zadna]
// Rozteč pevného roštu v zadní desce [mm]
rost_roztec = 22;
// Šířka žeber roštu [mm]
rost_zebro = 1.6;
// Hloubka lůžka pro kupovanou síťku v zadní straně rámu [mm]; o trochu méně než tloušťka síťky, aby ji sevřela
sitka_tl = 0.25;
// Tištěná síťka: rozteč vláken [mm] (otvor = rozteč - šířka vlákna)
tistena_roztec = 1.7;
tistena_vlakno = 0.5;
// Tloušťka tištěné síťky [mm]; celá leží na podložce, min. 0,4 = dva průjezdy po 0,2 mm
tistena_tl = 0.8;

/* [Táhlo – otočná vačka a tištěná šestihranná tyč] */
// Tyč: kulatá, na koncích šestihran; rozměr šestihranu přes plošky [mm]
tyc_s = 8;
// Délka jednoho dílu tyče [mm] (kolik se vejde na tiskovou podložku)
tyc_dil = 230;
// Šířka zastavovacích plošek vačky (na každou stranu od 0°, 90° a 180°) [°]
vacka_ploska = 12;

/* [Montážní deska na zeď – Fischer DuoPower 8 x 65 S (vrut 5 x 80 zápustný)] */
// Zadní (montážní) deska zůstává na zdi; přední kryt s lamelami se k ní přišroubuje zepředu.
// Tloušťka montážní desky [mm]; DuoPower 8x65 + vrut 80 => max 10 (vrut musí jít 70 mm do hmoždinky)
tl_desky = 8;
// Vodorovná rozteč vrutů do zdi (2 nahoře, 2 dole) [mm]
roztec_sroubu = 100;
// Osa vrutu od horní/dolní hrany desky [mm]; co nejmenší = hmoždinka co nejdál od otvoru ve zdi
vrut_od_okraje = 8;
// Průměr průchozího otvoru pro vrut [mm]
prumer_sroubu = 5.5;
// Průměr zápustné hlavy vrutu [mm]
hlava_sroubu = 10;

/* [Přední kryt k montážní desce – 4 otočné zámky na čtvrt otáčky] */
// Vodorovná rozteč zámků (2 nahoře, 2 dole) [mm]
roztec_klicu = 50;
// Přesah příčky v aretaci [mm] = stálý přítlak krytu (menší = lehčí chod, větší = pevnější)
klic_predpeti = 0.3;
// Hloubka aretace [mm]: o kolik musí příčka vyjet, aby se zámek povolil
aretace_hl = 0.35;
// Tloušťka plného dna zámku v montážní desce [mm] (leží celou plochou na podložce)
dno_zamku = 2.4;

/* [Pojistné hřebínky] */
// Výška výstupků západky na prstech hřebínku [mm]; větší = drží pevněji, jde ztuha zatlačit
hrebinek_zapadka = 0.35;

/* [Hidden] */
$fn = 48;
eps = 0.01;

W = sirka; H = vyska; D = hloubka; st = stena; sb = bok; sd = tl_desky;
N = pocet_lamel; p = roztec; c = sirka_lamely; t = tloustka_lamely;
phic = uhel_zavreni;

// --- lamela a její osa -------------------------------------------------
d_osa = 5;  r_osa = d_osa/2;
v_off = r_osa - t/2;          // osa leží nad střednicí lamely -> spodek rovný pro tisk
r_hub = 2.8;                  // výztužné žebro kolem osy
gap   = 0.8;                  // vůle krajních lamel k rámu v zavřené poloze
y_ax  = st + (D - st)/2;      // hloubka osy lamel

// --- kinematika (kulisa: čep lišty ve vidlici ramene) -------------------
alpha  = phic/2;              // rameno svírá s lamelou alpha -> symetrický zdvih
e      = 7.5;                 // vodorovná vzdálenost čepu lišty od osy lamely
r_cep  = 2;                   // čep lišty Ø4
s_max  = e*tan(alpha);        // polovina zdvihu lišty
zdvih  = 2*s_max;
L_arm  = e/cos(alpha) + 2.2;  // délka ramene (vidlice přesahuje nejvzdálenější polohu čepu + rozšířené ústí)
usti_l = 1.8;                 // délka rozšířeného ústí vidlice
usti_w = 1.0;                 // o kolik se ústí rozšíří na každou stranu
w_arm  = 2*r_cep + 0.4 + 2*2.2;
t_arm  = 3;

// --- odvozené svislé rozměry --------------------------------------------
up  = (c/2 - t/2)*sin(phic) - v_off*cos(phic) + t/2;  // přesah zavřené lamely nad osu
dn  = (c/2 - t/2)*sin(phic) + v_off*cos(phic) + t/2;  // přesah pod osu
cav_h = (N-1)*p + up + dn + 2*gap;                    // světlá výška průduchu
tb  = (H - cav_h)/2;                                  // horní/dolní okraj
z1  = tb + gap + dn;
function zl(i) = z1 + i*p;

// --- vodorovné rozměry ---------------------------------------------------
x_cav0 = bok_protejsi; x_cav1 = W - sb;               // průduch (mechanismus je u x_cav1)
x_cc   = (x_cav0 + x_cav1)/2;                         // střed průduchu = střed límce a síťky
cav_w  = x_cav1 - x_cav0;
x_lam0 = x_cav0 + 0.5; x_lam1 = x_cav1 - 0.5;         // tělo lamely
x_kom0 = x_cav1 + st;  x_kom1 = W - st;               // komora mechanismu
x_arm0 = x_kom0 + 0.5; x_arm1 = x_arm0 + t_arm;
x_bar0 = x_arm1 + 0.5; x_bar1 = x_kom1 - 0.5;         // ovládací lišta

// --- ovládací lišta ------------------------------------------------------
y_bar0 = st + 0.4;  y_bar1 = D - 0.6;     // vzadu místo pro síťku přes komoru
y_pin  = y_ax + e;
bar_top0 = zl(N-1) + 8;
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

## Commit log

2026-09-27 Větrací mřížka s žaluzií ovládanou táhlem zespodu
    Parametrická 3D tisknutelná mřížka 180x250 mm (OpenSCAD). Lamely
    ovládá svislá lišta ve skryté boční komoře, ze spodku rámu visí
    tyčka Ø6 mm s rukojetí. Obsahuje STL díly natočené pro tisk,
    náhledy, animaci mechanismu, kontrolu kolizí a návod v README.
    Claude-Session: https://claude.ai/code/session_01Gga4jzc2Sn42S15f7Fkkgo
    [kontrola.scad, lamela.stl, lista.stl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]
2026-09-27 Táhlo nalevo: parametr ovladani (vlevo/vpravo), výchozí vlevo
    Celá sestava se pro levou variantu zrcadlí, kinematika a kontrola
    kolizí se nemění. Přegenerovaná STL, obrázky a README.
    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
    [lamela.stl, lista.stl, mrizka.scad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]
2026-09-27 Uchycení na zeď pro Fischer DuoPower 8x65 S, šrouby M3x10, odkazy na nákup
    - vruty 5x80 zapuštěné na patku u zdi (svěrná tloušťka 8 mm, 72 mm
    v hmoždince), zahloubení Ø12 s tisknutými krytkami
    - spojení zadní desky šrouby M3x10 s válcovou nebo zápustnou hlavou
    - osa tyčky posunuta na y=12, aby se červík M3x5 celý schoval v liště
    (dřív by vyčníval a drhl o čelo rámu); zesílená spojka tyček
    - detail uchycení v řezu, README s odkazy na nákup
    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
    [krytka.stl, lamela.stl, lista.stl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]
2026-09-27 Pevný rošt a síťka proti hmyzu (kupovaná i tištěná)
    - zadní deska: pevný rošt v průduchu, lem pro okraj síťky, západky
    v límci pro přítlačný rámeček
    - nové díly ramecek_sitky (pro kupovanou síťku 139x205 mm) a
    sitka_tistena (rámeček s tištěnou síťkou, oka 1,2 mm)
    - oprava: šrouby M3x10 s válcovou hlavou jdou zepředu skrz rám do zadní
    desky pod krytku; dřívější nálitky na zadní desce trčely pod
    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
    [krytka.stl, lamela.stl, lista.stl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]
2026-09-27 Síťka sevřená mezi rámem a zadní deskou místo rámečku v límci
    Přítlačný rámeček se západkami v límci síťku pořádně nesevřel (vůle
    0,4 mm, okraj se mohl vysunout) a mohl vypadnout do otvoru ve zdi.
    Síťka teď leží v lůžku 0,25 mm na zadní straně rámu a zadní deska ji
    sevře všemi 6 šrouby; rošt zůstává hned za ní. Tištěná síťka je nově
    první vrstvy zadní desky (zadni_deska_se_sitkou.stl), díly
    ramecek_sitky a sitka_tistena odpadají.
    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
    [krytka.stl, lamela.stl, lista.stl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]
2026-09-27 Montážní deska zůstává na zdi, přední kryt se sundá kvůli síťce
    - vruty do zdi jen skrz montážní desku (6 mm), zápustné hlavy v rovině
    jejího čela; přední kryt ji celou zakryje
    - přední kryt se k montážní desce přišroubuje 4x M3x10 zepředu pod
    krytkami (závit celou tloušťkou desky); výměna síťky bez sundání
    mřížky ze zdi
    - pojistné hřebínky mají přítlačná žebra, aby držely lamely i v
    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
    [kontrola.scad, krytka.stl, lamela.stl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]
2026-09-27 Otočné klíče místo šroubů M3, tištěná síťka celá na podložce
    - přední kryt drží na montážní desce 4 tištěné otočné klíče (čtvrt
    otáčky): zápustná hlava se zářezem na minci, dřík skrz kryt a
    nalepené křídlo, které se v desce otočí za okraj štěrbiny s
    předpětím 0,15 mm; klíče zůstávají v krytu, krytky a M3 odpadají
    - tištěná síťka je plochá mřížka 0,4 mm: vlákna v obou směrech leží na
    podložce, nic se netiskne do vzduchu
    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
    [klic.stl, kridlo_klice.stl, krytka.stl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]
2026-09-27 Klíč z jednoho kusu bez lepidla, otvor ve zdi 158x208, vruty dál od otvoru
    - otočný klíč je jeden kus: kuželový spodek křídla (tiskne se bez
    podpěr) dosedá do kuželového lůžka v montážní desce; svislá štěrbina v
    krytu a vodorovná v desce drží klíč v krytu bez lepení
    - síťku při nasazování drží 4 tištěné trny místo lepicí pásky, síla
    žeber hřebínků je parametr (hrebinek_zebra) místo lepidla
    - nové parametry otvor_sirka/otvor_vyska (158 x 208), límec se počítá z
    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
    [klic.stl, kridlo_klice.stl, lamela.stl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]
2026-09-27 Zámek krytu podle Camloc/Dzus, západka hřebínků, širší průduch a síťka
    - zámek: plochý klíč tištěný naplocho (tah podél vrstev), dvě listové
    pružiny v montážní desce prohnuté o 0,3 mm dávají přítlak, aretační
    drážka zamčenou polohu drží, svislá/vodorovná štěrbina drží klíč v krytu
    - pojistné hřebínky: rozdělené pružné prsty s výstupky zacvaknou do
    drážek v krytu (drží i v sundaném krytu)
    - protější boční okraj krytu 8 mm místo 20: průduch 152 x 206 mm,
    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
    [klic.stl, lamela.stl, lista.stl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]
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2026-09-27 Nový zámek: profil D, šroubovitý náběh, půlkruhová aretace; souměrný kryt
    - klíč s profilem D (kulatý dřík Ø8, půlkulatá příčka Ø5 se zaoblenými
    konci) tištěný naplocho na rovné ploše
    - montážní deska 8 mm: pružné pásky se šroubovitým náběhem (~7°),
    půlkruhové lůžko aretace přesně podle příčky, dorazy proti přetočení
    a otáčení špatným směrem
    - protější boční okraj krytu zpět na 20 mm (souměrný kryt); límec má
    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
    [klic.stl, lamela.stl, lista.stl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]
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
